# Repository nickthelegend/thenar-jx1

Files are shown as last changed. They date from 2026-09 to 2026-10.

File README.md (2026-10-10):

<p align="center">
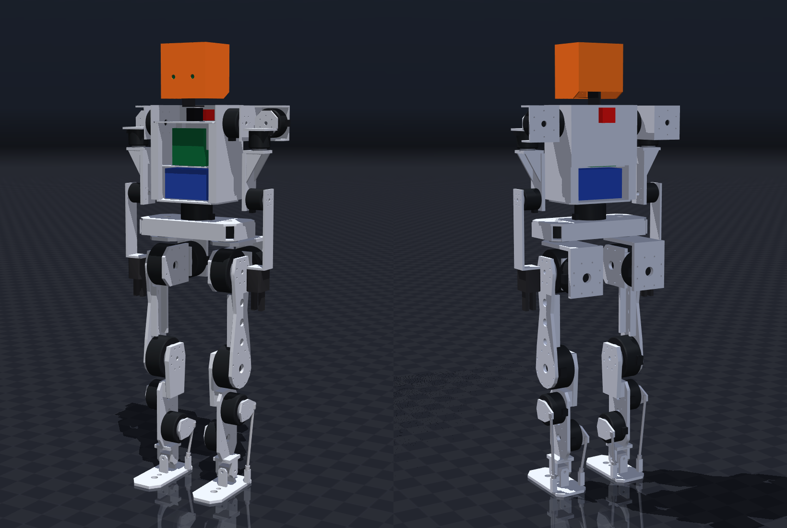
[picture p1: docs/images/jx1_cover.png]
JX1 humanoid robot, fully assembled — front three-quarter and back three-quarter views rendered from the CAD
  
</p>

<h1 align="center">JX1 — a humanoid robot you can build in India</h1>

<p align="center">
  <b>1.23 m tall · 33.6 kg · 23 joints · walks at 0.5–0.8 m/s in simulation · ≈ ₹7.1 lakh in parts</b><br>
  Full CAD, strength analysis, parts list with Indian suppliers, wiring, firmware, simulation and a trained walking
  controller, all in this repository.
</p>

<p align="center">
  <a href="docs/assembly_guide.md"><b>Assembly guide</b></a> ·
  <a href="docs/build_guide.md"><b>What to buy / machine / print</b></a> ·
  <a href="bom/cost_summary.md"><b>Cost</b></a> ·
  <a href="docs/final_robot_specification.md"><b>Specification</b></a> ·
  <a href="#try-it-in-simulation-free-no-hardware"><b>Try it in simulation</b></a> ·
  <a href="docs/open_issues.md"><b>Open issues</b></a>
</p>

---

## New: JX0, the small STS3215 humanoid you can build now

<p align="center">
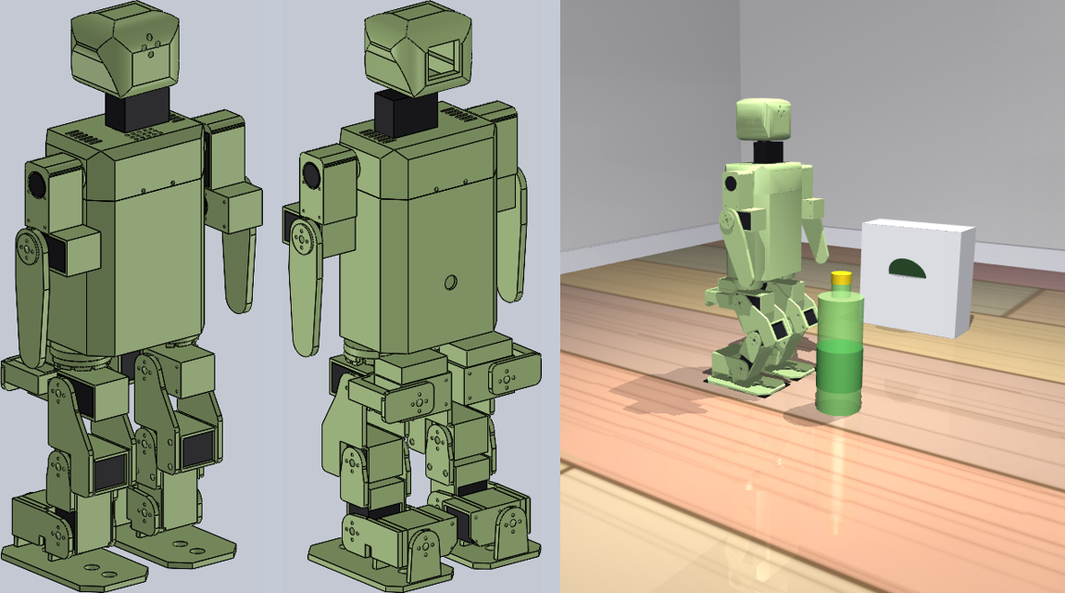
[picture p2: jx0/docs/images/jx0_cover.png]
JX0 v0.4: SolidWorks front and back views with double-sided leg joints, and the simulated robot walking with its arms swinging
  
</p>

JX1's parts cost about ₹7 lakh. **[JX0](jx0/README.md)** is the small version you can build now: 46 cm tall, printed
in pastel green, **every one of its 17 joints a Feetech STS3215 12 V servo**, styled after a friend's working robot,
with the same **double-sided leg joints** (every leg servo held on its horn and its rear hub by a U-bracket). It
**walks with its arms swinging, stays up through hard pushes, and talks (Claude)**, for **₹58,215** in parts. It uses
the same design pipeline as JX1:
- the SolidWorks CAD is built by script;
- the servo sizing passes;
- every printed leg part passes a finite-element check under the simulated walking and push loads;
- all 14 walking gaits pass in simulation;
- the robot's own program runs on the simulated robot.

<p align="center">
  <a href="jx0/README.md"><b>JX0 overview</b></a> ·
  <a href="jx0/results/images/jx0_demo.mp4"><b>Demo film</b></a> ·
  <a href="media/jx0_assembly.mp4"><b>Assembly film</b></a> ·
  <a href="jx0/bom/JX0_cost_estimate.pdf"><b>Cost estimate (8-page PDF)</b></a> ·
  <a href="jx0/docs/build_guide.md"><b>Build guide</b></a> ·
  <a href="jx0/results/verification.md"><b>Verification</b></a> ·
  <a href="media/jx0_cad_timelapse.mp4"><b>SolidWorks timelapse</b></a>
</p>

---

## Watch it go together

<p align="center">
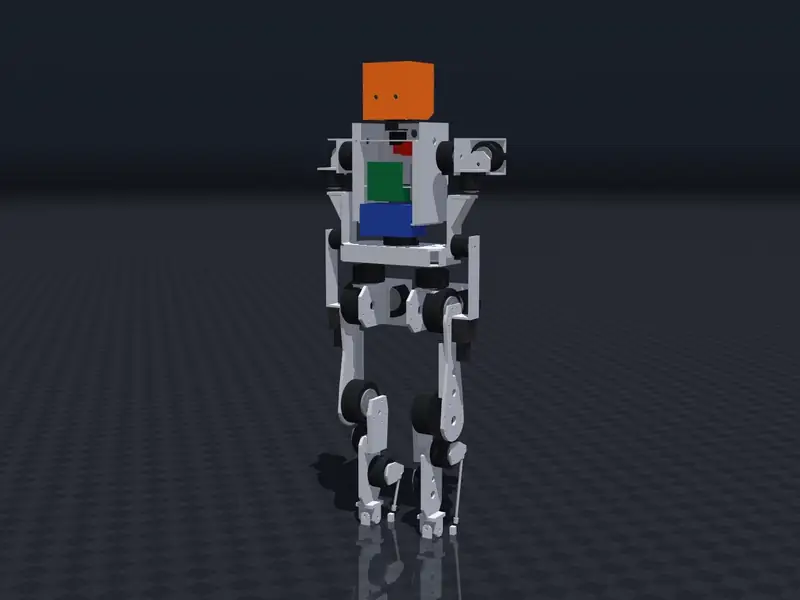
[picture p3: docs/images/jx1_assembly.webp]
Animated assembly of JX1: all 87 parts fly into place in build order, then the robot walks
  <br>
  <sub>Time-lapse of the assembly film. <b><a href="https://github.com/nickthelegend/thenar-jx1/raw/main/media/jx1_assembly.mp4">Download the full 96-second film with step titles (MP4, 13 MB)</a></b>:
  all 87 CAD parts come together in 22 steps, then the robot walks (MuJoCo simulation of the same CAD).</sub>
</p>

The film is rendered from the real SolidWorks parts in their verified positions (`tools/media/assembly_film.py`,
MuJoCo renderer). The titles are a [HyperFrames](https://hyperframes.heygen.com) composition synced to it
(`media/assembly-film/`). Every step is also written out with a picture in the
**[step-by-step assembly guide](docs/assembly_guide.md)**.

---

## Contents

1. [What is JX1?](#what-is-jx1)
2. [Honest status](#honest-status)
3. [JX1 at a glance](#jx1-at-a-glance)
4. [How JX1 works, in plain words](#how-jx1-works-in-plain-words)
5. [What it costs](#what-it-costs)
6. [What is metal, what is 3D-printed](#what-is-metal-what-is-3d-printed)
7. [How to build one: the whole path](#how-to-build-one-the-whole-path)
8. [Try it in simulation (free, no hardware)](#try-it-in-simulation-free-no-hardware)
9. [How it was designed and checked](#how-it-was-designed-and-checked)
10. [Repository map](#repository-map)
11. [Reproduce everything](#reproduce-everything)
12. [Glossary](#glossary)
13. [FAQ](#faq)
14. [Open issues, safety, licence](#open-issues-safety-licence)

---

## What is JX1?

JX1 is a **full-size walking humanoid robot**, about as tall as a 7-year-old child. It was designed from scratch to
answer one question:

> *What is the cheapest practical humanoid that someone in India can actually build, with parts they can actually
> buy, in shops they can actually reach?*

So every choice here favours buying over inventing, where that's possible:

- **Motors:** off-the-shelf RobStride actuators, the same kind small commercial humanoids use. There is no custom
  gearbox to design.
- **Structure:** flat aluminium plates that any laser-cutting or CNC job shop in India can cut from a drawing.
- **Electronics:** boards you can order from Robu, Evelta and similar shops.
- **Software:** open tools (MuJoCo, ROS 2, PyTorch). A walking controller is already trained and included.

Everything a builder needs is in the repository: 3D CAD (SolidWorks), STEP files and PDF drawings for the job shop,
strength calculations for every structural part, a costed parts list with Indian suppliers and links, wiring diagrams,
firmware for the motor-control boards, a physics simulation, and the trained walking policy.

## Honest status

**Current version: [v1.0-alpha](docs/releases/v1.0-alpha.md) (2026-09-24): design complete, buy list still being
decided.** JX1 has not been built yet. It is complete **on the computer**:

| Done (on the computer) | Not done yet (needs a real robot) |
|---|---|
| ✅ All 87 parts designed in CAD; every joint moved through its range and checked for collisions | ⬜ Actuator bolt patterns confirmed on real motors ([OI-1](docs/open_issues.md)) |
| ✅ Every structural part strength-checked (FEA), all pass in aluminium | ⬜ Real job-shop quotes (the metal prices are estimates) |
| ✅ Costed parts list, India-sourced | ⬜ Assembly, wiring, first power-on |
| ✅ Physics simulation: stands, squats, walks, survives pushes | ⬜ Walking on a real floor |
| ✅ Walking controller trained (reinforcement learning), tested on the full CAD model, over ROS 2 and against an emulated motor-control board | ⬜ Tuning on real hardware |

Every number in this repository carries a label, so you always know how much to trust it:
**VERIFIED** (checked against a source or a CAD measurement), **MEASURED**, **CALCULATED** (from a model),
**ESTIMATED**, **ASSUMED**, **UNVERIFIED**.

## JX1 at a glance

| | |
|---|---|
| Height, mass | 1.23 m, 33.6 kg (CAD, all parts) |
| Joints (degrees of freedom) | **23**: legs 2 × 6, waist 1, arms 2 × 4, neck 2 |
| Legs | hip yaw, roll and pitch meet at one point; knee; **parallel ankle** (2 motors on the shin drive the foot through push-rods) |
| Motors | 21 × RobStride (RS04 120 N·m, RS03 60 N·m, RS06 36 N·m, RS02 17 N·m, RS00 14 N·m peak) + 2 bus servos in the neck |
| Brain | NVIDIA Jetson Nano 4 GB: runs the walking controller 50 times a second |
| Motor control | 2 × Teensy 4.1 "hub" boards, 6 CAN buses, 500 updates per second |
| Sensors | BNO085 IMU (balance) in the pelvis, IMX219-83 stereo camera in the head, encoders in every motor |
| Battery | 13S2P Li-ion, 48 V nominal, 468 Wh: ≈ 1.4 h walking at 0.5 m/s (1.1 h at 0.8 m/s), ≈ 5 h standing (CALCULATED) |
| Structure | 6061-T6 aluminium plates (7075-T6 for the hip-yaw brackets); head and grippers 3D-printed |
| Walking (simulation) | learned controller: trained up to 0.8 m/s forward, side-steps ±0.39 m/s, turns up to 0.87 rad/s; survives 29–60 N·s shoves while walking, 26–55 N·s standing; stands still at 73 W. Scripted gait: 0.3–0.52 m/s |
| Cost | ₹7,12,481 in parts (₹8,19,353 with 15 % contingency); the motors are 77 % of it |

Full details: the generated **[FINAL ROBOT SPECIFICATION](docs/final_robot_specification.md)**.

## How JX1 works, in plain words

Think of the robot like a body:

| Body part | In JX1 | What it does |
|---|---|---|
| **Skeleton** | aluminium plates and brackets | holds everything in place and carries the robot's weight |
| **Muscles** | 21 *actuators*: motor + gearbox + position sensor + driver in one round can | each one turns one joint to the angle it is told, with the stiffness it is told |
| **Nerves** | CAN bus: two twisted wires that daisy-chain from motor to motor | carries commands out and joint angles back, 500 times a second |
| **Spinal cord** | 2 × Teensy 4.1 hub boards | talk to the motors fast and safely, and stop everything if something goes wrong |
| **Brain** | Jetson Nano running a neural-network *policy* | decides where each leg joint should go next, 50 times a second |
| **Inner ear** | IMU in the pelvis | senses tilt and rotation, so the robot knows if it is falling |
| **Eyes** | stereo camera in the head | depth vision (for later: navigation and manipulation) |
| **Heart** | 468 Wh battery + BMS + fuses | feeds 48 V to the motors and 5 V to the computers |
| **Reflex** | red E-stop button | cuts motor power and makes every joint go soft |

```mermaid
flowchart LR
  CMD["Joystick / ROS 2<br/>'walk forward 0.5 m/s'"] --> J["Jetson Nano<br/>walking policy, 50 Hz"]
  J -- "USB: joint targets" --> HA["Hub A (Teensy 4.1)<br/>left leg, left arm, waist"]
  J -- "USB: joint targets" --> HB["Hub B (Teensy 4.1)<br/>right leg, right arm, neck"]
  HA -. "joint states + IMU" .-> J
  HB -. "joint states" .-> J
  IMU["IMU in pelvis"] -- SPI --> HA
  HA -- "3 CAN buses, 500 Hz" --> MA["11 actuators"]
  HB -- "3 CAN buses, 500 Hz" --> MB["10 actuators"]
  MA -- "joint angles + speeds" --> HA
  MB -- "joint angles + speeds" --> HB
  ES["E-stop"] -. "cuts motor power + damping" .-> HA
  ES -.-> HB
```

**How it walks.** Nobody hand-wrote the walking. A neural network (the *policy*) learned to walk by trial and error in
a physics simulation of the exact CAD robot. The method is reinforcement learning (PPO), about 20,000 simulated steps
per second on one laptop. The policy was trained with random pushes, rough ground, small sensor delays, and randomised
friction and masses, so it doesn't depend on the simulation being perfect. Every 20 ms it reads the joint angles and the IMU and
outputs a target angle for each of the 12 leg joints. The motors then hold those angles like stiff springs. See
[rl/README.md](rl/README.md).

**Where the joints are.**

| Joint | Per side | Actuator | Range (left side) |
|---|---|---|---|
| Hip yaw (turn the leg) | 1 | RS06 | −40° … +45° |
| Hip roll (leg out to the side) | 1 | RS03 | −25° … +45° |
| Hip pitch (leg forward/back) | 1 | RS04 | −115° … +35° |
| Knee | 1 | RS04 | 0° … 120° |
| Ankle pitch + roll (parallel: 2 motors together) | 2 | 2 × RS06 | −55° … +30°, ±20° |
| Waist yaw | (1 total) | RS06 | ±90° |
| Shoulder pitch / roll | 2 | 2 × RS02 | −170° … +60° / −10° … +150° |
| Shoulder yaw / elbow | 2 | 2 × RS00 | ±90° / −135° … +5° |
| Neck yaw + pitch | (2 total) | 2 × ST3215 servo | — |

The single source of truth for joint names, axes, limits and motor directions is
[`simulation/joint_map.yaml`](simulation/joint_map.yaml). The CAD, simulation, ROS 2 and firmware are all generated
from it or checked against it.

## What it costs

Landed cost in India, including GST and import duty (from [`bom/master_bom.csv`](bom/master_bom.csv); prices checked
2026-09; metal parts ESTIMATED until quoted):

| Group | ₹ | What's in it |
|---|---:|---|
| Legs | 4,18,394 | 12 actuators + metal leg parts + ankle linkage |
| Arms | 1,52,688 | 8 actuators + arm plates |
| Electronics | 49,048 | Jetson Nano, 2 × Teensy 4.1, IMU, CAN parts, camera |
| Power | 31,606 | battery cells, BMS, switch, E-stop, fuses, DC-DC |
| Torso | 31,522 | waist actuator, torso frame |
| Head, pelvis, manufacturing | 29,223 | head shell + neck servos, pelvis box, filament and consumables |
| **Total** | **7,12,481** | + 15 % contingency = **₹8,19,353** |

- **Printable 9-page component list and cost estimate:** [bom/JX1_cost_estimate.pdf](bom/JX1_cost_estimate.pdf) (generated from the BOM by `bom/make_cost_report.py`).
- **Motors are 77 % of the cost** (₹5,45,998). Buying the same RobStride units through a China distributor would save
  about ₹1.87 lakh ([cost summary](bom/cost_summary.md)).
- **You can build it in two phases.** Phase 1 is the walking lower body (legs + pelvis + compute + power) for about
  ₹5.1 lakh. The upper body comes later.

## What is metal, what is 3D-printed

**Short answer: don't 3D-print the skeleton.** Every structural part was strength-checked both ways. Aluminium passes
everywhere. Printed carbon-fibre nylon (PA-CF) fails everywhere, and PETG would be worse.

| Printed PA-CF safety factor | Aluminium safety factor (needs ≥ 1.5) |
|---|---|
| hip-yaw bracket **0.08** ❌ | 7075-T6: **1.77** ✅ |
| shin **0.35** ❌ | 6061-T6: **3.37** ✅ |
| pelvis **0.90** ❌ | 6061-T6: **2.90** ✅ |
| upper arm **0.73–1.23** ❌ | 6061-T6: **5.99** ✅ |

What you **do** print:

1. **PETG fit-check copies** of every metal part (`manufacturing/fit_check/`). Bolt them to the real motors first to
   check the holes and clearances. Then order the metal. This is cheap insurance.
2. **Real printed parts** that carry little load: the head shell (PETG-CF), neck bracket and grippers (PA-CF, TPU
   pads), covers and battery box.

The full table (every part, material, process, file) is in the **[build guide](docs/build_guide.md)**. STEP files
and A3 PDF drawings for the job shop are in **[manufacturing/](manufacturing/index.md)**.

## How to build one: the whole path

You don't need to be an expert, but you need patience and care. The high-power parts (48 V, 468 Wh battery,
120 N·m motors) can hurt you. Go in this order:

| # | Stage | What you do | Guide |
|---|---|---|---|
| 0 | **Understand it** | read this page, watch the film, run the simulation | [simulation](#try-it-in-simulation-free-no-hardware) |
| 1 | **Lock the motor interfaces** | get the official RobStride drawings (or measure one of each size), put the bolt patterns into `tools/cad/params.py`, regenerate the CAD | [build guide §6](docs/build_guide.md#6-build-order), [OI-1](docs/open_issues.md) |
| 2 | **Bench electronics** | one motor on a USB-CAN adapter: set its ID, read feedback; flash the Teensy hub firmware; test the E-stop | [electrical wiring §6](docs/electrical_wiring.md#6-bring-up-checklist-electrical), [`firmware/`](firmware/) |
| 3 | **Fit-check prints** | print the PETG copies, bolt them to the real motors, fix anything that doesn't fit | [build guide §4](docs/build_guide.md#4-printing-notes) |
| 4 | **Order parts** | send the STEP + PDF set to a laser/CNC shop; buy the motors and electronics from the BOM | [manufacturing/](manufacturing/index.md), [BOM](bom/master_bom.csv) |
| 5 | **Assemble** | 22 steps: pelvis → hips → thighs → knees → shins → ankles → feet → waist → torso → electronics → arms → head | **[assembly guide](docs/assembly_guide.md)** |
| 6 | **Wire it** | power trunks with 58 V fuses, 6 CAN buses, E-stop with two independent paths | [electrical wiring](docs/electrical_wiring.md) |
| 7 | **First power-on** | on a gantry, feet off the ground: one joint at a time, zero offsets, limits, motor directions | [assembly guide, part E](docs/assembly_guide.md#part-e--after-the-assembly-first-power-on-the-safe-order), [safety](docs/safety_architecture.md) |
| 8 | **Stand, then walk** | still on the harness: damping → stand → weight shifts → the learned walking policy over ROS 2 | [rl/README.md](rl/README.md#real-robot-hardware-bridge-and-hardware-in-the-loop-ros2_wssrcjx1_hw) |

**The 22 assembly steps** (each one has a picture and instructions in the [assembly guide](docs/assembly_guide.md)):

| Lower body | | Torso, power, arms, head | |
|---|---|---|---|
| 1 | Pelvis torsion box | 13 | Waist actuator |
| 2 | Hip-yaw actuators | 14 | Torso frame |
| 3 | Hip-yaw brackets (7075) | 15 | Battery + electronics |
| 4 | Hip-roll actuators | 16 | Shoulder-pitch actuators |
| 5 | Hip-roll brackets | 17 | Shoulder brackets + roll actuators |
| 6 | Hip-pitch actuators | 18 | Shoulder-yaw actuators |
| 7 | Thighs | 19 | Upper arms + elbows |
| 8 | Knee actuators | 20 | Forearms + grippers |
| 9 | Shins | 21 | Neck |
| 10 | Ankle motors + cranks | 22 | Head + stereo camera |
| 11 | Ankle cross + feet | | |
| 12 | Push-rods | | |

<p align="center">
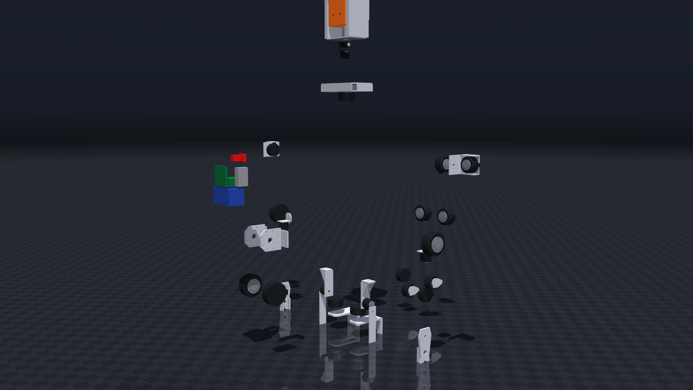
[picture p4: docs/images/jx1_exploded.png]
JX1 exploded view
  
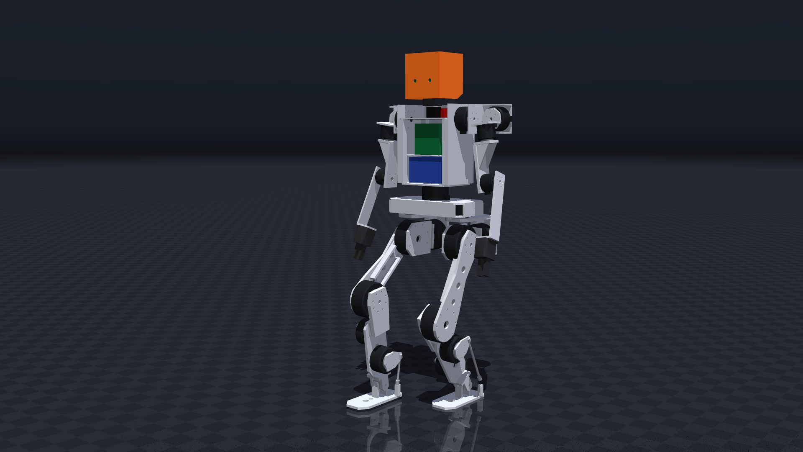
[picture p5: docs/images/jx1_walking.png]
JX1 walking in simulation
  
</p>

## Try it in simulation (free, no hardware)

You can drive the robot around with your keyboard in about five minutes. Any recent Windows, Linux or Mac computer
works. No GPU is needed to *run* the trained controller.

```bash
git clone https://github.com/nickthelegend/thenar-jx1.git
cd thenar-jx1
python -m venv rl/.venv
```

Then install and start it. On **Windows**:

```bash
rl/.venv/Scripts/python -m pip install -r rl/requirements.txt
rl/.venv/Scripts/python rl/play.py
```

On **Linux / macOS** (on macOS, use `mjpython` from the same venv instead of `python` for the viewer):

```bash
rl/.venv/bin/python -m pip install -r rl/requirements.txt
rl/.venv/bin/python rl/play.py
```

A MuJoCo window opens with the full CAD robot standing on the floor. Click the window, then:

| Key | Does |
|---|---|
| ↑ / ↓ | walk faster forward / backward (0.1 m/s per press) |
| ← / → | turn left / right |
| `,` / `.` | step sideways |
| Space | stop |
| Backspace | reset to standing |

Want more? `rl/sim2sim.py` runs the standard test scenarios. `rl/push_test.py` shoves the robot.
`rl/train.py` trains your own policy (a GPU helps). ROS 2 users: `ros2 launch jx1_bringup mujoco_sim.launch.py` and
drive `/cmd_vel`. All of it is in **[rl/README.md](rl/README.md)**.

## How it was designed and checked

The design went through the same loop a professional team would use. Each step leaves evidence files in the repo:

```text
requirements ─► reference robots (29 humanoids) ─► actuator selection ─► leg maths (IK, ZMP walking, dynamics)
     ─► parametric CAD (SolidWorks, driven from Python) ─► every joint moved through its range, collisions checked
     ─► strength (voxel FEA, every structural part, static + fatigue) ─► mass + cost roll-up ─► back to the start
     ─► simulation model generated from the CAD ─► walking, pushes ─► reinforcement-learning controller ─► ROS 2 + firmware
```

| Area | Result | Evidence |
|---|---|---|
| CAD | 46 native parametric parts, fully constrained sketches, global variables; `JX1_LowerBody`, `JX1_UpperBody`, `JX1_Robot` assemblies with limit-mated joints | `CAD/`, `verification/cad_build_*.json` |
| Motion verification (SolidWorks vs analytic kinematics) | legs 25/25 poses each at 0.0000 mm / 0.0000°, 24/24 collision-free inside the coupled ankle limits; upper body 36/36 exact and collision-free; whole robot 13/13 exact, 11/11 collision-free inside the controller limits (pre-arm-redesign, OI-25); overhead arm range checked in MuJoCo on the CAD shapes, 49/49 agreement with SolidWorks (OI-16) | `verification/*motion_verification.json`, `verification/mujoco_arm_range.json`, images |
| Structure (voxel FEA, actuator-capped loads) | every structural part passes in 6061/7075 (SF static 1.77–14.4, fatigue 1.58–24.7); every printed PA-CF variant fails (0.07–1.23) | [structural report](calculations/results/structural/report.md) |
| Actuator margins (CAD masses) | at 0.8 m/s the learned controller keeps hips and knees within the 1.5× peak-torque policy (knee 89 of 120 N·m, hip roll 48 of 60); the ankle motors are the tightest: ankle pitch at 82 % of the linkage capability, capped at 80 % by the hub firmware (OI-21); the scripted ZMP gait meets it up to 0.52 m/s, at 0.79 m/s its hip yaw needs 37 N·m vs 36 N·m (OI-2) | [final spec](docs/final_robot_specification.md), `calculations/results/iter2_C_cad_masses/` |
| Simulation | MuJoCo model from the CAD (33.61 kg, CoACD hulls): standing, squat, ZMP walking 4/4 gaits, push recovery; URDF + xacro | `verification/mujoco_*.json`, `verification/xacro_check.json` |
| Learned walking | default `jx1_walk_stand_v7`: 8/8 scenarios upright on flat and rough ground (0.8 m/s command → 0.75–0.77 m/s), 118/130 (flat) and 119/130 (rough) commands tracked with 0 falls, pushes 29–60 N·s walking and 26–55 N·s standing, stands still (0 foot lift-offs); verified over ROS 2 and through the hub-firmware twin (HIL: 0.68 m/s at a 0.8 m/s command with the 80 % torque caps). Weak spot: slow forward walking undershoots (84 % of 0.3 m/s through the HIL chain, 93 % of 0.4 m/s over ROS 2). Isaac Lab task offline-checked, not run (UNVERIFIED) | [rl/README.md](rl/README.md), `rl/policies/jx1_walk_stand_v7/REPORT.md` |
| Manufacturing | 24 STEP files, 14 A3 drawings (PDF), 24 PETG fit-check STLs, 3 print STLs | [manufacturing/index.md](manufacturing/index.md) |
| Cost (India, landed) | ₹7,12,481; ₹8,19,353 with 15 % contingency; actuators 77 % | [bom/cost_summary.md](bom/cost_summary.md) |
| Power | 13S2P 468 Wh with the learned controller: standing 73 W → 5.1 h; walking 274 W at 0.5 m/s → 1.37 h, 347 W at 0.8 m/s → 1.08 h; peak battery current 15.9 A (BMS limit 40 A) | `rl/policies/jx1_walk_stand_v7/power.json`, `calculations/results/iter2_C_cad_masses/power_budget.json` |

## Repository map

| Folder | What's inside |
|---|---|
| [`docs/`](docs/) | **start here**: [assembly guide](docs/assembly_guide.md), [build guide](docs/build_guide.md), [final spec](docs/final_robot_specification.md), [architecture](docs/architecture.md), [electrical wiring](docs/electrical_wiring.md), [safety](docs/safety_architecture.md), [risk register](docs/risk_register.md), [open issues](docs/open_issues.md) |
| [`manufacturing/`](manufacturing/index.md) | files for the job shop: STEP, PDF drawings, PETG fit-check STLs, print STLs |
| [`bom/`](bom/) | [master_bom.csv](bom/master_bom.csv) (every part, supplier, link, price), [cost_summary.md](bom/cost_summary.md) |
| `CAD/` | native parametric SolidWorks parts and assemblies (`JX1_Robot`, `JX1_LowerBody`, `JX1_UpperBody`), drawings |
| `calculations/` | leg model, inverse kinematics, ZMP walking, dynamics, parallel ankle, power budget; `structural/` voxel FEA |
| [`actuators/`](actuators/actuator_selection.md) | why these motors: selection study, interface spec, catalogue |
| [`research/`](research/reference_robots.md) | 29 reference humanoids, Indian sourcing evidence |
| `requirements/` | [robot_requirements.yaml](requirements/robot_requirements.yaml): the living requirements |
| `simulation/` | [`joint_map.yaml`](simulation/joint_map.yaml) (kinematic contract), MuJoCo model and tests, Isaac Sim/Lab, meshes |
| [`rl/`](rl/README.md) | walking-controller training, export, tests, trained policies |
| `ros2_ws/` | ROS 2 packages: description (URDF/xacro), simulation node, policy node, bringup, hardware bridge |
| `firmware/` | Teensy 4.1 CAN-hub firmware: RobStride protocol, 500 Hz loop, watchdogs, E-stop |
| `tools/` | Python that drives SolidWorks (`swlib`, `cad`), builds the robot description (`sim`), renders the film (`media`) |
| `media/` | the assembly film ([jx1_assembly.mp4](media/jx1_assembly.mp4)) and its HyperFrames project |
| `verification/` | machine-readable evidence (JSON) and images for every check |

## Reproduce everything

Analysis (no SolidWorks needed):

```bash
python -m venv .venv
.venv/Scripts/python -m pip install -r requirements.txt
.venv/Scripts/python calculations/tests/test_kinematics.py
.venv/Scripts/python calculations/structural/test_voxel_fea.py
.venv/Scripts/python calculations/structural/run_structural.py
.venv/Scripts/python bom/build_bom.py
.venv/Scripts/python simulation/mujoco/validate_jx1.py
.venv/Scripts/python simulation/mujoco/walk_jx1.py
.venv/Scripts/python simulation/mujoco/push_jx1.py
.venv/Scripts/python tools/gen_final_spec.py
```

CAD (SolidWorks 2026 on Windows, driven through COM in a **dedicated session**, `tools/swlib/instance.py`, so other
SolidWorks work on the same machine is never touched; restart the JX1 session between the heavy steps, since the
whole-robot assembly needs ≈ 10 GB):

```bash
.venv/Scripts/python tools/cad/build_actuators.py XL L M S XS
.venv/Scripts/python tools/cad/build_leg_parts.py --side L
.venv/Scripts/python tools/cad/build_leg_parts.py --side R
.venv/Scripts/python tools/cad/build_upper_parts.py
.venv/Scripts/python tools/cad/build_upper_parts.py --side R
.venv/Scripts/python tools/cad/build_leg_assembly.py --sides LR
.venv/Scripts/python tools/cad/verify_leg_motion.py --side L --images
.venv/Scripts/python tools/cad/build_upper_assembly.py
.venv/Scripts/python tools/cad/verify_upper_motion.py --images
.venv/Scripts/python tools/cad/build_robot_assembly.py
.venv/Scripts/python tools/cad/verify_robot_motion.py --images
.venv/Scripts/python tools/cad/export_meshes.py
.venv/Scripts/python tools/cad/make_manufacturing.py
.venv/Scripts/python tools/sim/build_robot_description.py
.venv/Scripts/python tools/sim/check_xacro.py
```

The assembly film (MuJoCo render of the CAD, then the HyperFrames titles; needs ffmpeg and Node.js):

```bash
.venv/Scripts/python tools/media/assembly_film.py
.venv/Scripts/python tools/media/assembly_film.py --hero
.venv/Scripts/python tools/media/build_assembly_composition.py
cd media/assembly-film && npx hyperframes check && npx hyperframes render -o renders/jx1_assembly_master.mp4
```

RL training, export and the ROS 2 checks: [rl/README.md](rl/README.md).

## Glossary

| Word | Meaning |
|---|---|
| **Actuator** | a complete joint motor: brushless motor + planetary gearbox + position sensor (encoder) + driver electronics in one can. You send it a target angle and stiffness over CAN. |
| **DOF (degree of freedom)** | one way a joint can move. A human elbow has 1, a shoulder 3. JX1 has 23. |
| **Yaw / roll / pitch** | rotation about the vertical axis (turning), the forward axis (tilting sideways) and the sideways axis (nodding forward/back). |
| **Parallel ankle** | the ankle is moved by two motors mounted up on the shin, through two push-rods. The foot is light, and both motors share the load. |
| **N·m (newton-metre)** | torque, i.e. turning force. 120 N·m is like 12 kg hanging on a 1 m bar. |
| **FEA (finite element analysis)** | computer strength check: split a part into tiny cubes, apply the worst loads, find the highest stress. |
| **Safety factor (SF)** | strength ÷ worst stress. SF 2 means the part could take twice the worst load. JX1 requires ≥ 1.5 for aluminium, ≥ 2 for prints. |
| **Static / fatigue** | one big overload (a hard landing) / millions of small repeated loads (walking). Both have to pass. |
| **6061-T6 / 7075-T6** | common aerospace aluminium alloys. 7075 is about twice as strong and costs more. |
| **PETG, PA-CF, TPU** | 3D-printing plastics: everyday, carbon-fibre nylon (stiff and strong for a print), rubbery. |
| **STEP / STL / PDF drawing** | exact 3D model for machining / triangle mesh for 3D printing / 2D drawing with dimensions and tolerances. |
| **CAN bus** | a robust two-wire network used in cars. JX1 has 6 of them, each chaining 3–5 motors. |
| **BMS** | battery management system: protects the cells from over-charge, over-discharge and over-current. |
| **E-stop** | emergency stop: a big red button that cuts motor power and makes every joint go limp. |
| **IMU** | inertial measurement unit: senses rotation and acceleration, which is how the robot knows which way is down. |
| **ZMP** | zero-moment point: the classic way to plan a walking gait so the robot doesn't tip over. Used for the scripted gait. |
| **RL / PPO / policy** | reinforcement learning: the controller learns by trial and error in simulation. PPO is the algorithm. The result is a small neural network called the policy. |
| **Sim-to-sim** | testing the trained policy in a different, more detailed simulation than the one it was trained in: a check before trying it on hardware. |
| **HIL (hardware-in-the-loop)** | running the real control software against a software twin of the motor boards, to catch protocol and timing bugs early. |
| **URDF / xacro / MJCF** | robot description files (links, joints, masses, meshes) for ROS 2 / its macro form / MuJoCo. |
| **ROS 2** | Robot Operating System 2: the standard middleware robots use to pass messages between programs. |
| **MuJoCo** | a fast, accurate physics simulator, used here for testing and for training. |
| **Zero pose** | legs straight, feet flat, arms down: the reference where every joint angle is 0. |

## FAQ

**Can I build it with no engineering background?**
Yes, if you're careful and patient and have access to basic tools and a job shop for the metal. The assembly is
bolting parts together in the order of the [assembly guide](docs/assembly_guide.md). The hard engineering (sizing,
strength, kinematics, control) is already done and checked. The parts that can hurt you are the 48 V battery and
motors strong enough to pinch a finger badly. Read the [safety architecture](docs/safety_architecture.md) and always
test on a gantry.

**Can I 3D-print the whole thing to save money?**
No. The legs, pelvis, torso and arms fail the strength check as prints. A printed hip-yaw bracket would break at 8 % of
the worst load. See [what is metal, what is printed](#what-is-metal-what-is-3d-printed). Print the fit-check copies,
the head, the grippers and the covers.

**Why is it so expensive? Can I use cheaper motors?**
The 21 motors are 77 % of the cost. Each one is a complete joint: a high-torque brushless motor, a precision
planetary gearbox, bearings, an absolute encoder and a motor driver in one machined can. A walking humanoid's hips and
knees need 60–120 N·m peak torque while staying back-drivable, which hobby servos can't give. Of the ₹5.46 lakh,
₹3.86 lakh is RobStride's list price, ₹1.25 lakh is import duty (about 32 %: customs duty, surcharge and 18 % IGST) and
₹0.36 lakh is shipping; none are stocked in India. They are still the cheapest option found: ₹290 per N·m of peak
torque for the RS04, against ₹2,200–7,900 per N·m for integrated actuators sold in India
([actuator study](actuators/actuator_selection.md)). The cheapest real saving is buying the same RobStride units through
a China distributor (≈ ₹1.87 lakh less). A cheaper actuator can go in: the CAD is
parametric, so you change the actuator class in `tools/cad/params.py` and regenerate, then re-run the checks.

**Do I need SolidWorks?**
Only to *change* the design. To build it, you use the STEP files and PDF drawings in `manufacturing/`, which any CAD
program or job shop can open. The simulation, strength checks, BOM and controller all run without SolidWorks.

**Where do I buy things in India?**
Every line of [`bom/master_bom.csv`](bom/master_bom.csv) has a supplier and a link: Robu, Evelta, IndustryBuying,
bearinghouse.in and others. Metal parts go to a laser/CNC job shop (e.g. Robocon CNC, Makenica, or a local shop) with
the STEP + PDF set.

**How fast does it walk? How long does the battery last?**
In simulation the learned controller walks at up to 0.8 m/s (1.09 m/s at the edge of its range) and turns at up to
0.87 rad/s. The battery gives about 1.4 hours of walking at 0.5 m/s, or about 5 hours of standing (CALCULATED).
Real-world numbers will come from the first build.

**What is still unknown?**
Mainly the exact actuator bolt patterns (OI-1), real job-shop prices, and everything only a physical robot can show:
friction, backlash, cable wear, real walking. The full list is in [open issues](docs/open_issues.md) and the
[risk register](docs/risk_register.md).

**Can I help?**
Yes. Build parts of it, measure a RobStride actuator, get a job-shop quote, or try the controller. Anything that closes
an item in [open issues](docs/open_issues.md) moves the project forward.

## Open issues, safety, licence

- **Top open items:** actuator interface dimensions (OI-1); hip-yaw actuator vs top walking speed for the scripted gait
  (OI-2); bolted plate joints: CAD fastener geometry and prototype strain check (OI-17); drawings made under a
  SolidWorks Educational licence carry its "For Instructional Use Only" stamp (OI-19); whole-robot SolidWorks assembly
  re-check after the arm redesign (OI-25); ankle-motor torque headroom at the top walking speed, to be bench-checked
  (OI-21). All of them are in
  [open issues](docs/open_issues.md).
- **Safety:** this is a 34 kg machine with 120 N·m joints and a 468 Wh lithium battery. Always use the E-stop, a
  gantry or harness, and current-limited power for bring-up. See [safety architecture](docs/safety_architecture.md).
- **Licence:** not chosen yet. Until a licence file is added, ask the author before reusing the design commercially
  (OI-19).

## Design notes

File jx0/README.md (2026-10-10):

<p align="center">
  JX0 v0.4: SolidWorks front and back views with double-sided leg joints, and the simulated robot walking with its arms swinging
</p>

<h1 align="center">JX0: a walking, talking STS3215 humanoid you can build at home</h1>

<p align="center">
  <b>46 cm · 2.88 kg · 17 joints, every one a Feetech STS3215 12 V · double-sided leg joints · walks with its arms
  swinging · talks (Claude) · ₹58,215 in parts</b><br>
  3D-printed in pastel green, styled after a friend's working STS3215 robot. Full SolidWorks CAD, a verified walking
  simulation, a strength check of every leg part, the robot program and a parts list with Indian suppliers are all in
  this folder.
</p>

<p align="center">
  <a href="docs/build_guide.md"><b>Build guide</b></a> ·
  <a href="bom/jx0_bom.csv"><b>Parts list</b></a> ·
  <a href="bom/JX0_cost_estimate.pdf"><b>Cost estimate (8-page PDF)</b></a> ·
  <a href="../media/jx0_assembly.mp4"><b>Assembly film</b></a> ·
  <a href="docs/wiring.md"><b>Wiring</b></a> ·
  <a href="docs/bringup.md"><b>Bring-up</b></a> ·
  <a href="docs/software_setup.md"><b>Software</b></a> ·
  <a href="results/verification.md"><b>Verification</b></a> ·
  <a href="#try-it-on-your-pc">Try it on your PC</a>
</p>

---

## Watch it

<p align="center">
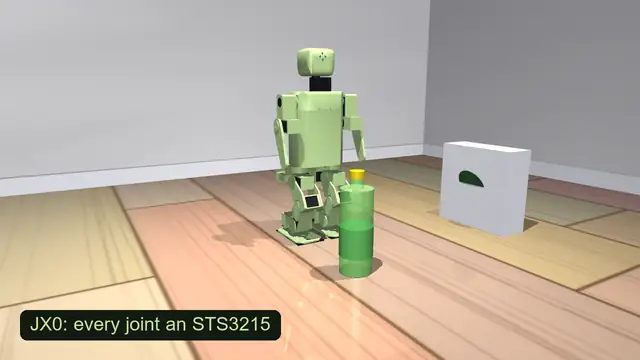
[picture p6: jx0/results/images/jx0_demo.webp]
Simulated JX0 waving, walking with its arms swinging, taking a hard side push and bumping a bottle out of its way
  <br>
  <sub><b><a href="results/images/jx0_demo.mp4">Demo film (MP4)</a></b>, staged like the reference video: JX0 walks on
  a wooden floor with its arms swinging, waves, takes a hard 0.96 N·s shove from the side and keeps going (in the
  <a href="results/verification.md">verification</a> it stays up through all 48 such shoves, timed across a whole
  step), and bumps a plastic bottle out of its way. The robot's own program (<code>software/jx0bot</code>, the same code that runs
  on the Pi) drives the SolidWorks robot in MuJoCo; the push and the bottle are plain physics.</sub>
</p>

## Watch it go together

<p align="center">
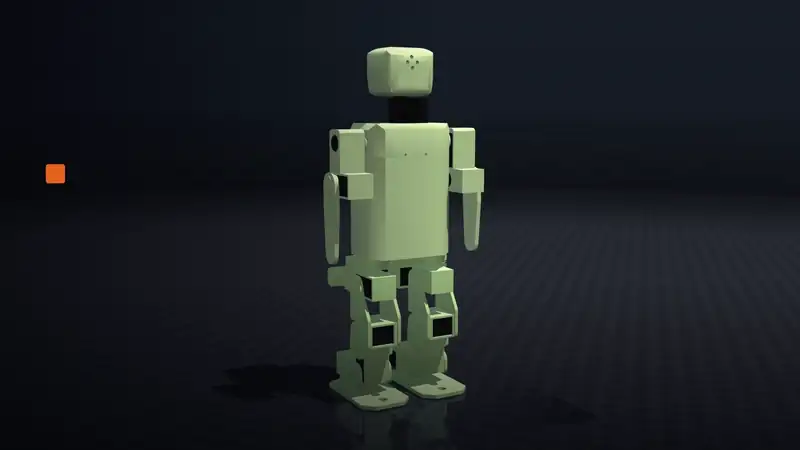
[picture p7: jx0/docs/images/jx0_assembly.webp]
Animated assembly of JX0: its 39 parts fly into place in build order, then the robot walks
  <br>
  <sub><b><a href="../media/jx0_assembly.mp4">Assembly film (MP4, 67 s)</a></b>: every SolidWorks part of JX0 flies into
  place in the order of the <a href="docs/build_guide.md">build guide</a>, 13 steps from the pelvis to the head, then the
  finished robot walks its verified gait. Rendered from the real part meshes (<code>tools/media/assembly_film_jx0.py</code>,
  MuJoCo) with HyperFrames titles (<code>media/jx0-assembly-film</code>), like the JX1 film. A still of every step:
  <code>docs/assembly/</code>.</sub>
</p>

<p align="center">
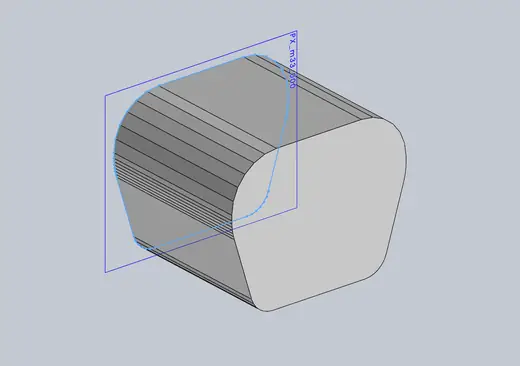
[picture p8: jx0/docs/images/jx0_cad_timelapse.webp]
SolidWorks timelapse: the JX0 parts built feature by feature, then the assembly
  <br>
  <sub>Built in SolidWorks by script (<code>cad/build_cad.py</code>, <code>cad/build_assembly.py</code>). The timelapses
  show the earlier single-sided legs: <a href="../media/jx0_cad_timelapse_v03.mp4">v0.3 (81 s)</a> ·
  <a href="../media/jx0_cad_timelapse.mp4">every version up to v0.3 (117 s)</a>.</sub>
</p>

## The legs: double-sided, like the reference robot

<p align="center">
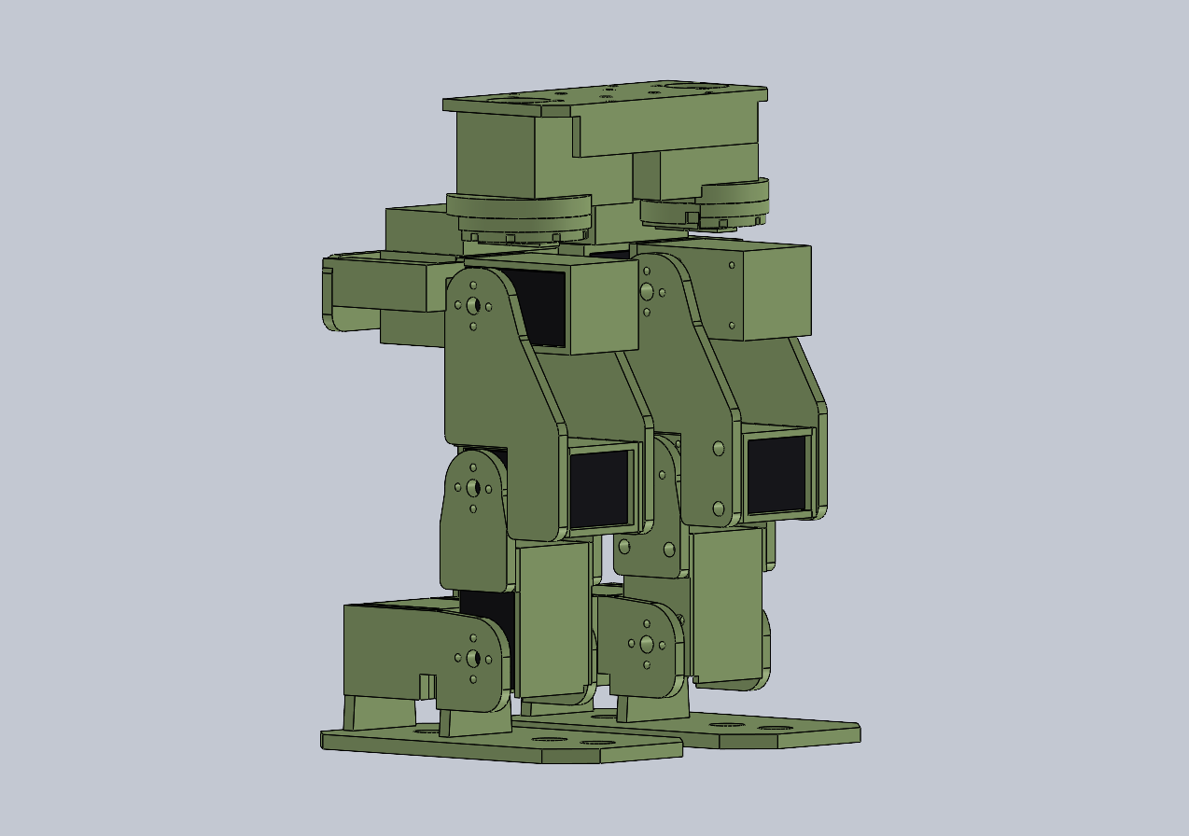
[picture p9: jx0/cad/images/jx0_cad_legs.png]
JX0 v0.4 legs in SolidWorks: every servo in a cage, the next part a U-bracket bolted to both faces of it
  
</p>

A servo joint can hold the next part in two ways:

- **Single-sided** (JX0 v0.3): the next part is one plate screwed to the servo's output horn. Every step bends that
  plate and the servo's output shaft. The plate is a cantilever, and printed plastic tires quickly when it is bent
  back and forth.
- **Double-sided** (v0.4, the reference robot): the STS3215 has a second, passive hub on its back face. The next part
  is a **U-bracket** with one arm on the horn and one on the rear hub, and the servo's body sits in a **cage** on the
  part before. The bending becomes a pair of forces in two arms 43 mm apart, and the servo's shaft is not bent at all.

The check (`verify/verify_strength.py`, `verify/verify_fea.py`) uses the loads from the walking simulation, every
10 ms, including 48 hard pushes and 42 walks on a randomly wrong robot model:

| | v0.3 single-sided plates | v0.4 U-brackets |
|---|---|---|
| Printed plate stress, walking | 30–85 MPa | 2–5 MPa |
| Fatigue safety factor (PETG ~15 MPa at 10⁶ cycles, ASSUMED) | **0.21–0.48: would crack** | **4.4–7.5** (beam model) |
| Servo output shaft bending (worst) | 2.3–3.6 N·m at every joint | none at the U-brackets; 0.55 N·m at the hip yaw (keeper) |
| Finite elements, every printed leg part | — | fatigue safety factor **2.1 or more**, strength **3.0 or more** |

The **hip yaw** cannot be a U-bracket: its servo stands under the body, as on the reference robot, with the hip-roll
servo right below it. So the pelvis holds the yaw disc from both sides instead:
- a **thrust ring** above the disc;
- a printed **keeper** below it, one per leg, whose lip runs under the disc's 3 mm flange. Four M2 screws clamp it to a
  boss on the pelvis.

The ring and the keeper take the leg's weight and bending as two pushes on the disc's rim, instant by instant
(`robustness.keeper_split`). The yaw servo's shaft is left with:

| | Normal walking | Hardest pushes |
|---|---|---|
| Thrust ring alone | 1.2 N·m | 2.6 N·m |
| Thrust ring + keeper | **0.10 N·m** | **0.55 N·m** |

This assumes the keeper has no play: layers of PTFE tape under the flange set it at assembly
([build guide](docs/build_guide.md), step 2). The keeper, the disc and the pelvis passed their own finite-element
checks (fatigue / strength: keeper 2.1 / 5.2, disc 2.4 / 3.6, pelvis 2.4 / 5.1). The hip yaw turns ±12°, more than
twice what the gaits use.

## The reference robot

JX0 copies a friend's robot: a small biped printed in pastel green with **every joint a 12 V STS3215**, a faceted
body, an exposed neck servo under a soft rounded head, and flat blade arms that swing as it walks. It walks steadily,
takes a shove, and knocks over a bottle on the way. JX0 matches that:

| On the reference robot | On JX0 v0.4 |
|---|---|
| 12 V STS3215 in every joint | 17 × Feetech STS3215 12 V (Evelta lists it as ST3215-C018, dual shaft), all on one serial bus |
| leg servos held on both faces: caged servo bodies, wide angled U-brackets, cross-pattern horn screws | the same: every leg pitch and roll joint is a cage + U-bracket on the horn and the rear hub |
| short legs under a wide body, hip servos hidden under it | 62 mm thigh, 58 mm shin; a skirt on the torso hides the hip-yaw servos |
| chamfered foot plates | chamfered 124 × 70 mm soles with a 1 mm rubber pad |
| pastel green print | eSun PLA-Matte Mint Green for the body; green PETG for the leg parts, which carry every step |
| faceted torso, vents on top, seam below the shoulders | octagonal torso with chamfered vertical edges; lower shell + chest cap with chamfered top edges, vent slots and a speaker grille |
| black neck servo exposed under the head | neck STS3215 standing on the chest cap |
| soft rounded head with four holes | rounded head, narrower at the chin, four holes in a diamond (the microphone listens through them) |
| shoulder servo in a bracket outside the chest, flat tapered arm | shoulder STS3215 in a hood outside the chest, elbow STS3215 in a box below it, a flat 6 mm paddle blade |
| walks with the arms swinging, takes a shove | gaits verified with a 1.6× counter-swing; stays up through every push up to 0.96 N·s ([verification](results/verification.md)) |
| runs off a 12.6 V bench supply | 3S LiPo, or a 12.6 V bench supply on the same XT60 |

## Honest status

| | Status |
|---|---|
| SolidWorks CAD: 22 printed parts + all 17 servos in the assembly | **done**, every part rebuilt by script, one body each, no errors |
| Parts colliding, standing or in motion (every gait frame and action, 1,373 poses; every joint over its full range) | **none** |
| Servo sizing (every leg joint, 5 gaits + 8 static cases), 2.88 kg robot | **passes**; the tightest is hip roll with a 1.46× margin |
| Strength of every printed leg part, finite elements under the simulated loads | **passes**: fatigue safety factor 2.1 or more, strength 3.0 or more (PETG data ASSUMED) |
| Walking in simulation, on the CAD masses and a servo model | **14 of 14 gaits pass** with arm swing (forward 0.05 m/s, backward, turns, side-steps) |
| Walking when the real robot differs from the model (servo stiffness, latency, backlash, IMU noise, mass, friction, slope) | **138 of 140** random walks pass (latency up to 20 ms) and **all 140 stay up**; with 40 ms latency 123 pass, all 140 stay up |
| The whole robot program, an 8-action mission, random realistic errors | **24 of 24** completed without a fall |
| Pushes mid-walk (48 timings each) | stays up through **every** push up to 0.96 N·s; 90 % at 1.2 N·s, 44 % at 1.44 N·s |
| Robot program (voice, Claude brain, walking, gestures) | **written, unit-tested (21 tests) and run in simulation**; not yet on hardware |
| Parts list | ₹58,215; STS3215 price and stock checked 2026-10-04 ([8-page cost estimate](bom/JX0_cost_estimate.pdf)) |
| Physical robot | **not built yet**: this is what the funding is for |

All of it is in the **[verification report](results/verification.md)**: what was checked, what it found and fixed, and
the honest limits (`python jx0/verify/run_all.py` re-runs everything in about 45 minutes). Unverified until the robot
is built, and the first things to check: a test U-bracket on a servo (the rear hub's screw pattern is ASSUMED equal to
the horn's), the M2 screw fit in the printed holes, the servo stiffness setting and the I2S audio overlay. Battery life
is about 73 minutes of walking (CALCULATED: 1.45 A average for the servos and the Pi).

## What it can do

| Ask it… | It… |
|---|---|
| "Hi!" / any question | answers out loud in one to three sentences (Claude) |
| "Walk forward five steps" / "go back" / "step left" | plays the gait blocks verified in simulation, arms swinging, with IMU balance on the stance leg |
| "Turn around" | repeats 10° turn blocks until the IMU says it has turned far enough |
| "Wave at me" | raises an arm up in front and wags the blade |
| "Look left" / "yes or no?" | turns its head; bows for yes, shakes its head for no |

## JX0 at a glance

| | |
|---|---|
| Height, mass | 46.0 cm, 2.88 kg (CAD) |
| Joints | 17 Feetech STS3215 12 V serial bus servos: 6 per leg, shoulder pitch and elbow per arm, neck yaw |
| Brain | Raspberry Pi 4 (2 GB): gaits and balance at 100 Hz, MPU6050 IMU, Vosk speech recognition, Piper voice, Claude over Wi-Fi |
| Power | 3S 2200 mAh LiPo straight to the servo bus (12 V servos); a 5 V UBEC for the Pi; or a 12.6 V bench supply |
| Structure | 22 printed parts, 847 g: pelvis and leg parts in PETG, printed near-solid (554 g); body, head and arms in PLA (293 g) |

## What it costs

| Group | ₹ |
|---|---|
| Servos: 17 × STS3215 | 41,123 |
| Electronics: Pi 4, microSD, servo driver, button, wiring | 9,151 |
| Structure: PLA and PETG filament, screws, inserts, rubber, PTFE tape | 4,123 |
| Power: LiPo, charger, UBEC, switch, wire, alarm | 3,122 |
| Voice: microphone, amplifier, speaker | 569 |
| Sensors: IMU | 127 |
| **Total** | **58,215** |

Line by line with store links: [bom/jx0_bom.csv](bom/jx0_bom.csv). The 17 servos are 71 % of the cost. JX0 is
₹8,215 over the original ₹50,000 target because every joint is an STS3215, as on the reference robot. The walking
needs 2.0 N·m at the hip roll (with the 1.25–1.5× margins), which rules out MG996R-class hobby servos, and the serial
bus servos also report their position, which the calibration and the balance loop use.

## How it works, in plain words

- **Walking.** A planner (the same one designed for JX1) works out where the body's balance point must be at every
  instant for a given step length and speed, then computes the 12 leg joint angles 100 times a second. The arms
  counter-swing with the opposite leg, like the reference robot. Those trajectories were run on a physics model of this
  exact robot, with a model of how the servos really behave (they give a little under load and slow down when pushed
  hard). Only the gaits that passed are shipped in `software/jx0bot/gaits/`. On the robot, the IMU corrects the ankles
  and hips as it walks.
- **Talking.** A button, or saying "hey robot", starts listening. Vosk turns speech into text on the Pi itself. Claude
  writes a short spoken reply and can call the robot's actions as tools. Piper speaks the reply sentence by sentence
  through the speaker under the chest grille.
- **One bus.** All 17 servos are chained on one serial bus from a small driver board on the Pi's USB. There's no PWM
  wiring, and every joint reports its angle.

## Try it on your PC

No hardware needed. Install the packages, then talk to the simulated robot by typing:

```bash
pip install -r jx0/software/requirements-pc.txt
```

```bash
cd jx0/software && python -m jx0bot.main --sim --text
```

It needs an `ANTHROPIC_API_KEY`. Without one, you can still run these:
- `python jx0/sim/demo_jx0.py` renders the demo film.
- `python jx0/sim/walk_jx0.py` reruns every walking check.
- `python jx0/cad/preview.py` builds and renders the robot from the geometry, with no SolidWorks needed.
- `python jx0/verify/run_all.py` reruns the whole verification.

## How it was designed and checked

| Step | Tool | Result |
|---|---|---|
| Design point: sizes, masses, joint ranges | [design_point.yaml](design_point.yaml) | every value labelled VERIFIED / CALCULATED / ESTIMATED / ASSUMED |
| Servo sizing | [analysis/sizing.py](analysis/sizing.py) → [results/sizing.md](results/sizing.md) | peak ×1.5 ≤ stall, RMS ×1.3 ≤ rated, inside the torque-speed line: **all pass** |
| CAD | [cad/geometry.py](cad/geometry.py) → SolidWorks by script | 22 printed parts, assembly with all 17 servos, masses fed back into the design point |
| Walking | [sim/walk_jx0.py](sim/walk_jx0.py) → [results/walking.json](results/walking.json) | 14/14 gaits with arm swing at 100 Hz: tilt ≤ 1.4°, final position error ≤ 10 mm, servo peaks ≤ 55 % of stall |
| Collisions | [verify/verify_cad.py](verify/verify_cad.py) | 0 clashes in 741 part pairs and 1,373 moving poses; every joint limit inside its collision-free range |
| Robustness | [verify/robustness.py](verify/robustness.py) | 140/140 random-error walks stay up (139 pass); 24/24 whole-program missions; pushes up to 0.96 N·s: 100 % stay up |
| Joint strength | [verify/verify_strength.py](verify/verify_strength.py) | single-sided plates would crack (fatigue SF 0.18–0.51); U-brackets 4.7–8.0 |
| Leg parts, finite elements | [verify/verify_fea.py](verify/verify_fea.py) | every printed leg part: fatigue SF ≥ 2.1, strength SF ≥ 3.0 ([stress maps](results/images)) |
| Power and timing | [verify/verify_power.py](verify/verify_power.py) | 1.44 A walking (≈ 73 min per charge), 2.5 A peak; the 100 Hz loop uses ~2 of 10 ms on a Pi 4 |
| Software | [software/tests](software/tests/test_jx0bot.py) | 21 unit tests: servo protocol bytes vs the Feetech manual, config, gait files, kinematics vs the model, Claude tool loop |
| Whole robot program | [sim/demo_jx0.py](sim/demo_jx0.py) | every action runs on the simulated robot; it takes a hard side push and bumps a bottle out of its way |

| Gait | Speed | Distance plan → sim | Heading error | Max tilt | Peak servo load |
|---|---|---|---|---|---|
| forward (10 steps) | 0.050 m/s | 0.255 → 0.245 m | 0.0° | 1.4° | 54 % |
| forward slow | 0.050 m/s | 0.195 → 0.188 m | 0.0° | 1.4° | 54 % |
| backward | 0.033 m/s | 0.130 → 0.121 m | 0.0° | 1.4° | 54 % |
| turn left 70° / right 70° | — | — | −3.4° / +3.4° | 1.4° | 55 % |
| side-step left | — | 0.060 → 0.057 m | 0.0° | 1.3° | 54 % |

## Folder map

| Path | What |
|---|---|
| `design_point.yaml` | the numbers everything else reads |
| `analysis/` | servo sizing |
| `cad/` | geometry, SolidWorks build scripts, `preview.py`, `render_cad.py`, `parts/*.SLDPRT`, `JX0_Robot.SLDASM`, `stl/` for printing |
| `sim/` | MuJoCo model, walking checks, demo film |
| `verify/` | collisions, robustness, strength, finite elements, power and timing checks; `run_all.py` writes [results/verification.md](results/verification.md) |
| `software/jx0bot/` | the robot program (see [software_setup.md](docs/software_setup.md)) |
| `bom/` | parts list and the cost PDF |
| `docs/` | build guide, wiring, bring-up, software setup |
| `results/` | sizing, walking and verification results, images and films |

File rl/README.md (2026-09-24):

# JX1 — trainable model (MuJoCo · Isaac Lab · ROS 2)

Phase 3 of JX1: the CAD-derived robot as a **reinforcement-learning-ready model** with one policy format that runs in
MuJoCo, Isaac Lab and ROS 2. The walking task, its conventions and the deployment gains live in one file,
[`config/jx1_walk.yaml`](config/jx1_walk.yaml); every other piece reads it.

```text
 SolidWorks CAD ──► tools/sim/build_robot_description.py ──► simulation/mujoco/jx1.xml   ros2_ws/.../jx1.urdf(.xacro)
                                                                   │                          │
            rl/config/jx1_walk.yaml (joints, default pose,         ▼                          ▼
            PD gains, obs/action layout, rewards, DR, PPO)   rl/ (MuJoCo, CPU-batched)   simulation/isaac/isaaclab (Isaac Lab)
                                                                   │  train.py → export.py    │  scripts/train.py → export_policy.py
                                                                   ▼                          ▼
                                             policy bundle: policy.onnx + policy.pt + policy_io.yaml
                                                                   │
                        ┌──────────────────────────────────────────┼───────────────────────────────┐
                        ▼                                          ▼                               ▼
              rl/sim2sim.py (full CAD MuJoCo,         ros2_ws: jx1_policy node  ◄──►  jx1_sim (MuJoCo node) / Isaac Sim ROS 2
              500 Hz, mesh-hull collisions)           /jx1/joint_states /jx1/imu /cmd_vel → /jx1/joint_command (or ros2_control)
```

## What is where

| Path | Contents | Status |
|---|---|---|
| `rl/config/jx1_walk.yaml` | task definition: 12 policy joints, default pose, deployment PD gains, action scale 0.25, 47-D observation, gait clock, commands, rewards, domain randomisation, PPO | source of truth |
| `rl/jx1_rl/assets.py` | CAD MJCF → training model (capsules/boxes fitted to the CoACD hulls, collision groups, gains, sensors, `home` keyframe) | tested |
| `rl/jx1_rl/env.py` | batched MuJoCo environment on `mujoco.rollout` (C++ thread pool), rewards, DR, pushes, resets | tested, ~20k policy steps/s on 8–11 threads |
| `rl/jx1_rl/ppo.py`, `rl/train.py` | PPO (rsl_rl algorithm: asymmetric actor-critic, running normalisers, GAE, adaptive LR), GPU update, left/right mirror loss (`jx1_rl/symmetry.py`) | tested |
| `rl/export.py` | TorchScript + ONNX (normaliser baked in) + `policy_io.yaml`, checked against the checkpoint | tested |
| `rl/sim2sim.py` | exported policy on the **full CAD model** (mesh hulls, 500 Hz, no DR), 7 command scenarios; optional sensing/actuation delay; per scenario: tracking, torque/speed margins, foot lift-offs, self-contact between robot bodies | tested |
| `rl/envelope.py`, `rl/push_test.py`, `rl/latency_test.py`, `rl/power_test.py` | command envelope (vx × wz, vx × vy grids, incl. self-contact), push recovery (walking and standing), latency sensitivity, electrical power / battery current / actuator thermal load, all on the CAD model | tested |
| `rl/report.py`, `rl/compare_policies.py`, `rl/play.py` | `REPORT.md` policy card per bundle, side-by-side comparison, keyboard driving in the MuJoCo viewer | tested (viewer: headless path) |
| `rl/tests/test_rl.py` | quaternion maths vs MuJoCo, ankle-polygon projection (numpy/ROS/torch), env determinism, training-vs-deployment observation parity, latency, hub ramp, MuJoCo/Isaac `policy_io` parity, hardware protocol/bridge/IMU, rough terrain, GAE/normaliser, ros2_control xacro, mirror maps vs MuJoCo physics, stand-mode clock gating | 15/15 pass |
| `simulation/isaac/isaaclab/` | Isaac Lab tasks `Isaac-Velocity-{Flat,Rough}-JX1-v0` (+ `-Play`), same obs/actions/rewards/DR; rsl_rl config, train and export scripts, offline API check, Isaac Sim ROS 2 bridge | offline-checked against Isaac Lab 2.3.2 + rsl_rl 3.1.2 and the bridge and USD import against Isaac Sim 5.1 sources (89/89); **not run in Isaac Sim** |
| `ros2_ws/src/jx1_policy` | ONNX policy runner (no training code) + ROS 2 node (WAIT → RAMP → WALK, HOLD on stale state) | runner tested; node see below |
| `ros2_ws/src/jx1_sim` | MuJoCo ROS 2 node: `/clock`, `/jx1/joint_states`, `/jx1/imu`, `/jx1/odom`, TF; applies `/jx1/joint_command` | see below |
| `ros2_ws/src/jx1_bringup` | `mujoco_sim.launch.py`, `isaac_sim.launch.py`, `ros2_control.launch.py`, controllers | see below |
| `tools/sim/gen_ros2_control.py` | `jx1.ros2_control.xacro` (mock / topic_based_ros2_control), `jx1_system.urdf.xacro`, `controllers.yaml` | generated |
| `ros2_ws/src/jx1_hw` | Jetson ↔ CAN-hub bridge (firmware USB protocol, parallel-ankle IK/FK, motor gains), hub-firmware digital twin, `hardware.launch.py` | protocol + bridge tested; HIL run on the emulator |
| `rl/ros2_check.py`, `rl/hw_loop_check.py`, `rl/ros2_env/build_ws.py` | end-to-end checks over real ROS 2 (sim node / hardware bridge + emulated hubs), from the source tree or with `--launch` from a colcon install (`mujoco_sim.launch.py`, `ros2_control.launch.py`, `hardware.launch.py hil:=true`) | run on this machine (RoboStack Jazzy) |

## Trained policies (final CAD model, 33.61 kg)

Each bundle in `rl/policies/` has `policy.onnx`, `policy.pt`, `policy_io.yaml` and every check result, summarised in its
`REPORT.md`. A copy for ROS 2 lives in `ros2_ws/src/jx1_policy/policies/`. The **default is `jx1_walk_stand_v7`** for
the ROS 2 policy node, the launch files, the hardware launch, the Isaac Sim bridge and the rl tools
(`jx1_rl.DEFAULT_POLICY`); `jx1_walk_rough` was the default before it.

<!-- policies:start -->
| | `jx1_walk_flat` | `jx1_walk_rough` | `jx1_walk_sym_latency` | `jx1_walk_stand` | `jx1_walk_stand_sym` | `jx1_walk_stand_v7` |
|---|---|---|---|---|---|---|
| trained | walk_v2_final it 3000 | walk_v3_rough it 4000 | walk_v4_sym_latency it 5000 | walk_v5_stand it 4800 | walk_v6_stand_sym it 5600 | walk_v7_stand_free it 6400 |
| sim2sim flat | 7/7 upright; 0.5 m/s -> 0.50, turn 0.5 -> 0.47 rad/s, peak torque 90% | 8/8 upright; 0.5 m/s -> 0.52, turn 0.5 -> 0.49 rad/s, peak torque 81% | 7/7 upright; 0.5 m/s -> 0.51, turn 0.5 -> 0.49 rad/s, peak torque 70% | 8/8 upright; 0.5 m/s -> 0.52, turn 0.5 -> 0.46 rad/s, peak torque 83% | 8/8 upright; 0.5 m/s -> 0.49, turn 0.5 -> 0.42 rad/s, peak torque 74% | 8/8 upright; 0.5 m/s -> 0.48, turn 0.5 -> 0.50 rad/s, peak torque 84% |
| sim2sim rough | 7/7 upright; 0.5 m/s -> 0.50, turn 0.5 -> 0.47 rad/s, peak torque 95% | 8/8 upright; 0.5 m/s -> 0.53, turn 0.5 -> 0.49 rad/s, peak torque 79% | 7/7 upright; 0.5 m/s -> 0.52, turn 0.5 -> 0.50 rad/s, peak torque 72% | 8/8 upright; 0.5 m/s -> 0.53, turn 0.5 -> 0.47 rad/s, peak torque 86% | 8/8 upright; 0.5 m/s -> 0.50, turn 0.5 -> 0.43 rad/s, peak torque 76% | 8/8 upright; 0.5 m/s -> 0.48, turn 0.5 -> 0.50 rad/s, peak torque 81% |
| envelope flat | 99/130 tracked, 0 falls; fwd +1.13, back -0.59, yaw +0.85/-0.82 | 109/130 tracked, 0 falls; fwd +1.08, back -0.57, yaw +0.84/-0.86 | 102/130 tracked, 0 falls; fwd +1.05, back -0.58, yaw +0.89/-0.92 | 98/130 tracked, 0 falls; fwd +1.12, back -0.62, yaw +0.83/-0.86 | 117/130 tracked, 0 falls; fwd +1.09, back -0.59, yaw +0.78/-0.86 | 118/130 tracked, 0 falls; fwd +1.09, back -0.55, yaw +0.87/-0.88 |
| push (N s) | 12.7-21.6 (fwd 21.6, back 14.5, left 12.7, right 17.8) | 15.9-44.1 (fwd 32.8, back 35.6, left 15.9, right 44.1) | 11.7-39.8 (fwd 39.8, back 26.7, left 11.7, right 28.1) | 22.5-55.8 (fwd 36.1, back 38.4, left 22.5, right 55.8) | 29.5-57.7 (fwd 44.1, back 46.4, left 29.5, right 57.7) | 29.1-60.0 (fwd 53.4, back 42.2, left 29.1, right 60.0) |
| HIL (hub twin) | fwd 95% of 0.3 m/s, turn 74% of 0.3 rad/s | fwd 95% of 0.3 m/s, turn 88% of 0.3 rad/s | fwd 95% of 0.3 m/s, turn 72% of 0.3 rad/s | fwd 97% of 0.3 m/s, turn 75% of 0.3 rad/s | fwd 88% of 0.3 m/s, turn 71% of 0.3 rad/s | fwd 84% of 0.3 m/s, turn 92% of 0.3 rad/s |
| turn 0.3 tracking | 85% (no delay), 70% (20 + 10 ms) | 101% (no delay), 94% (20 + 10 ms) | 84% (no delay), 74% (20 + 10 ms) | 83% (no delay), 75% (20 + 10 ms) | 80% (no delay), 73% (20 + 10 ms) | 102% (no delay), 90% (20 + 10 ms) |
| self-contact, envelope flat | - | 3/130 commands (1 in the trained range): left_shin_link|right_shin_link (2), left_foot_link|right_foot_link (1) | - | 0/130 commands (0 in the trained range): none | 0/130 commands (0 in the trained range): none | 5/130 commands (0 in the trained range): left_shin_link|right_shin_link (3), left_shin_link|right_foot_link (1), left_foot_link|right_foot_link (2) |
| self-contact, envelope rough | - | 3/130 commands (1 in the trained range): left_shin_link|right_shin_link (2), left_foot_link|right_foot_link (1) | - | 0/130 commands (0 in the trained range): none | 0/130 commands (0 in the trained range): none | 4/130 commands (1 in the trained range): left_shin_link|right_shin_link (2), left_foot_link|right_foot_link (2) |
| envelope rough | - | 108/130 tracked, 0 falls; fwd +1.09, back -0.56, yaw +0.84/-0.86 | 98/130 tracked, 0 falls; fwd +1.07, back -0.58, yaw +0.89/-0.93 | 94/130 tracked, 0 falls; fwd +1.13, back -0.61, yaw +0.83/-0.86 | 117/130 tracked, 0 falls; fwd +1.11, back -0.59, yaw +0.78/-0.87 | 119/130 tracked, 0 falls; fwd +1.10, back -0.56, yaw +0.87/-0.88 |
| stand -> walk 0.5 -> stand | - | upright, 2.50 foot lift-offs/s in the last 2 s | - | upright, 0.00 foot lift-offs/s in the last 2 s | upright, 0.00 foot lift-offs/s in the last 2 s | upright, 0.00 foot lift-offs/s in the last 2 s |
| stand (zero command) | - | 2.51 foot lift-offs/s, drift 0.05 m, 163 W | - | 0.00 foot lift-offs/s, drift 0.00 m, 79 W | 0.00 foot lift-offs/s, drift 0.00 m, 79 W | 0.00 foot lift-offs/s, drift 0.00 m, 73 W |
| power 0.5 / 0.8 m/s | - | 283 W / 368 W | - | 313 W / 382 W | 284 W / 363 W | 274 W / 347 W |
| push standing (N s) | - | 19.2-36.1 | - | 27.7-47.8 | 11.7-51.6 | 26.2-55.3 |
| HIL 0.8 m/s | - | 0.70 m/s, upright | - | 0.70 m/s, upright | 0.70 m/s, upright | 0.68 m/s, upright |
<!-- policies:end -->

- `jx1_walk_flat`: 1500 iterations on the placeholder model, then 1500 on the final CAD model (flat floor).
- `jx1_walk_rough` (default until `jx1_walk_stand_v7`): `jx1_walk_flat` fine-tuned for 1000 iterations on the rough
  heightfield. It is better on flat ground too. It leaves more torque headroom (peaks at 71–73 % against the hubs' 80 % cap), takes about twice the push
  impulse, has no yaw drift and tolerates latency.
- `jx1_walk_sym_latency` (experiment): `jx1_walk_rough` + 1000 iterations with the left/right mirror loss, 0–15 ms
  sensing / 0–10 ms actuation latency and half the entropy bonus. It came out slightly worse: 102 vs 109 commands
  tracked, 72 vs 88 % turn tracking through the HIL chain, 11.7 N·s vs 15.9 N·s worst push, and back to 84 %
  tracking of 0.3 rad/s turns. The rough policy had already lost the yaw drift and tolerates 40 ms + 20 ms latency, so
  it stays the default. Kept for reference; not installed with the ROS 2 package.
- `jx1_walk_stand` (experiment, OI-27): `jx1_walk_rough` + 800 iterations with the stand mode (clock features 0 below a
  command norm of 0.1, both feet down, no swing target) and 20 % zero commands. It really stands: 0 foot lift-offs/s
  instead of 2.5, 79 W instead of 163 W (4.7 h instead of 2.3 h on the pack), and it settles within 2 s after walking.
  It also takes larger pushes (22.5–55.8 N·s walking, 27.7–47.8 N·s standing) and has no leg self-contact over the
  envelope. But it tracks leftward side-steps and slow turns worse: 98 vs 109 commands, 0.3 rad/s turns at 83 % vs
  101 %, HIL turn 75 % vs 88 %. So `jx1_walk_rough` stays the default until a stand-mode policy matches its tracking.
- `jx1_walk_stand_sym` (experiment): `jx1_walk_stand` + 800 iterations with 10 % zero commands and a mild mirror loss
  (0.2). It keeps the stand mode (79 W, settles after walking) and has the widest envelope so far: 117/130 on flat and on
  rough ground, symmetric side-steps (±0.36 m/s), 29.5–57.7 N·s walking pushes and no self-contact. Its weak points:
  slow turns at 80 %, HIL 88 % forward / 71 % turn, −0.03 rad/s yaw drift while walking, and only 11.7 N·s forward push
  while standing, because the both-feet-down contact reward penalised recovery steps. `walk_v7` drops that stand-mode
  contact target (`gait.stand_contact_reward: none`) and weights yaw tracking 0.8.
- **`jx1_walk_stand_v7` (default)**: `jx1_walk_stand_sym` + 800 iterations without a stand-mode contact target
  (`gait.stand_contact_reward: none`, so it may step to recover) and yaw tracking weighted 0.8. Against `jx1_walk_rough`:
  - Standing: it stands still at 73 W (5.1 h on the pack, vs 163 W / 2.3 h) and settles after walking.
  - Envelope: widest so far, 118/130 flat and 119/130 rough, with side-steps ±0.39 m/s and turns ±0.87 rad/s.
  - Pushes: 29–60 N·s walking and 26–55 N·s standing, against 16–44 and 19–36.
  - Turns: 0.3 rad/s tracked at 102 % (90 % with 20 + 10 ms delay); HIL turn 92 % vs 88 %.
  - Power: walking takes less (274 / 347 W at 0.5 / 0.8 m/s).
  - Slow forward walking undershoots: HIL 84 % of 0.3 m/s vs 95 %, ROS 2 93 % of 0.4 m/s.
  - At 0.8 m/s the ankle pitch peaks at 82 % of the linkage capability (ankle motor 34 N·m without the hub cap). Through
    the hub's 80 % caps it still walks 0.68 m/s upright.
  - Self-contact: shins and feet graze (≤ 0.8 mm hull overlap) in 4–5 of 130 commands, mostly beyond the trained
    side-step range.
- Every bundle's `policy_io.yaml` carries the hip-yaw toe-out coupling (`hip_yaw_toe_out_max_rad`, OI-24), applied by
  every runner. The learned gaits never reach it (22.9° max toe-out sum against the 40° limit).
- Table generated by `rl/compare_policies.py <bundles>`. "HIL" is the hardware-in-the-loop run through `hw_node` and the
  hub-firmware twin.

## Train in MuJoCo (this machine: Windows, RTX 3050 6 GB, i5-13420H)

```bash
py -3.13 -m venv rl/.venv
rl/.venv/Scripts/python -m pip install torch==2.14.0 --index-url https://download.pytorch.org/whl/cu126
rl/.venv/Scripts/python -m pip install -r rl/requirements.txt
rl/.venv/Scripts/python rl/tests/test_rl.py
rl/.venv/Scripts/python rl/train.py --num-envs 1024 --iterations 3000 --run my_run        # rl/runs/my_run/
rl/.venv/Scripts/python rl/export.py --checkpoint rl/runs/my_run/model_latest.pt           # rl/policies/jx1_walk_flat/
rl/.venv/Scripts/python rl/sim2sim.py                                                      # full CAD model check + GIF
```

Resume or fine-tune on a regenerated CAD model with `--resume rl/runs/<run>/model_latest.pt`.

**Numerical note (MEASURED):** with the Newton solver's line search capped at 10 iterations the model injected energy
after falls (robots launched to hundreds of metres, 5/6 seeds); `ls_iterations >= 20` fixed it with no speed cost, so
the task uses 50/50.

### Rough ground

`rl/config/jx1_walk_rough.yaml` inherits the flat task (`base:` key) and replaces the floor with a 16 m heightfield of
2 m tiles: flat, ±2 cm uneven floor, domes/bowls up to 8°, and ±2 cm step strips (thresholds, cable covers). Every
non-step tile returns to zero at its edges, so the only discontinuities are the step edges (≤ 4 cm). Robots spawn over
the whole map; base height, foot clearance and the fall check are measured above the local ground; leaving the map ends
the episode without penalty. The observation stays blind (same 47-D vector), so the rough policy fine-tunes from the flat
one and deploys through the same `policy_io.yaml`, ROS 2 node and hardware bridge.

```bash
rl/.venv/Scripts/python rl/train.py --config rl/config/jx1_walk_rough.yaml --resume rl/runs/<flat run>/model_latest.pt --iterations <n>
rl/.venv/Scripts/python rl/sim2sim.py --policy rl/policies/jx1_walk_rough --terrain rl/config/jx1_walk_rough.yaml
```

### Robustness checks

- `rl/sim2sim.py [--terrain ...]`: 7 command scenarios on the full CAD model (mesh hulls, 500 Hz, hub target ramp);
  velocity tracking, tilt, peak torque / effort limit and peak joint speed / speed limit per scenario.
- `rl/push_test.py`: 0.1 s torso force pulse while walking at 0.5 m/s, bisection of the largest survived impulse per
  direction (same method as `simulation/mujoco/push_jx1.py` for the model-based controller). Interim policy on the
  placeholder-torso model: 11.7–23.4 N·s, vs 6.6–7.8 N·s for the fixed-footstep ZMP controller.
- `rl/envelope.py`: constant-command walks over a vx × wz and a vx × vy grid, from inside the training ranges to beyond
  them. For each command it records falls, tracking and torque margin, and writes `envelope.json` and `envelope.png`. The
  whole grid takes about a minute on 4 processes.
- `rl/power_test.py`: battery power, current and actuator RMS current vs rated for standing and walking, with the
  electrical model of `calculations/run_power_budget.py` (ankle motors through the linkage), plus foot lift-offs.
- Stand and self-contact metrics (every `sim2sim.py` / `envelope.py` rollout): foot lift-offs per second, swing fraction
  and base travel (stepping in place, OI-27), and every contact between two robot bodies on the CAD hulls (leg-leg OI-7,
  hip-yaw brackets OI-24, arm-thigh OI-18). The detector reports the hip-yaw bracket contact at 22° toe-out per hip, as
  the OI-24 sweep found.
- `rl/report.py`: gathers every check of a bundle (training curves, sim-to-sim, envelope, pushes, power, ROS 2, HIL)
  into the bundle's `REPORT.md`.

## Train in Isaac Lab (offline-checked, not yet run in Isaac Sim)

```bash
cd <IsaacLab> && ./isaaclab.sh -p -m pip install -e <repo>/simulation/isaac/isaaclab
./isaaclab.sh -p <repo>/simulation/isaac/isaaclab/scripts/train.py --task Isaac-Velocity-Flat-JX1-v0 --headless --num_envs 4096
./isaaclab.sh -p <repo>/simulation/isaac/isaaclab/scripts/train.py --task Isaac-Velocity-Rough-JX1-v0 --headless   # terrain generator
# deployment bundle straight from the checkpoint, on any machine with rl/.venv (no Isaac Sim needed):
rl/.venv/Scripts/python simulation/isaac/isaaclab/scripts/export_offline.py --checkpoint <log>/model_2999.pt --out rl/policies/jx1_walk_flat_isaac
rl/.venv/Scripts/python rl/sim2sim.py --policy rl/policies/jx1_walk_flat_isaac     # the Isaac-trained policy on the MuJoCo CAD model
```

Isaac Sim does not fit the design machine (RTX 3050 6 GB, 24 GB RAM, full system drive), so these tasks have not been
run. They are **checked offline against the Isaac Lab 2.3.2 sources and rsl_rl 3.1.2**:

```bash
git clone --depth 1 --branch v2.3.2 https://github.com/isaac-sim/IsaacLab.git <dir>/IsaacLab-2.3.2
rl/.venv/Scripts/python -m pip download rsl-rl-lib==3.1.2 --no-deps -d <dir>      # unzip the wheel to <dir>/rsl_rl_src
rl/.venv/Scripts/python simulation/isaac/isaaclab/scripts/offline_check.py --isaaclab <dir>/IsaacLab-2.3.2 --rsl-rl <dir>/rsl_rl_src
```

`offline_check.py` mocks the Omniverse modules (as Isaac Lab's own docs build does) and imports the real Isaac Lab code.
It checks all four tasks (89/89 pass, report in
[`offline_check.json`](../simulation/isaac/isaaclab/offline_check.json)):
- Every env and runner config instantiates, and `validate()` passes.
- Every manager term resolves as Isaac Lab resolves it at start-up (signature, scene entities against the robot the URDF
  importer builds).
- Every observation, reward and termination term runs on a fake scene whose attribute names are checked against the
  real data classes.
- Policy and critic observations equal the MuJoCo task's (47 and 55 values).
- The action term produces the MuJoCo targets on every physics substep: clamp, ankle polygon, hub ramp, delay, reset.
- Actuators cover all 23 joints with the task gains.
- The scripts' imports and keyword arguments match the library signatures.
- The offline exporter matches `rsl_rl`'s `ActorCritic.act_inference`.
- With `--isaacsim <sparse clone of isaac-sim/IsaacSim v5.1.0>`, it checks the Isaac Sim ROS 2 bridge
  (`scripts/ros2_bridge.py`). Every OmniGraph node type must exist as an `.ogn` definition, every connected or set
  attribute must exist with matching types, "target" inputs must be set as path lists, and every Isaac Sim Python call
  must match its source signature. `simulation/isaac/import_jx1.py` (URDF → USD) is checked the same way against the URDF
  importer: its import-config fields, command names and arguments.

What the check found and what was fixed:
- **Deployment bug:** under rsl_rl ≥ 3 (Isaac Lab ≥ 2.3) the observation normaliser moved into the policy. The export
  script therefore wrote an ONNX without it, and the deployed policy would have received raw observations.
  `export_policy.py` is fixed. `export_offline.py` reads both checkpoint layouts.
- **Runner config:** `obs_groups` is now set, so the critic gets the privileged group. The deprecated
  `empirical_normalization` is dropped on ≥ 2.3. Actions are clipped at ±100, as in MuJoCo.
- **Action term:** after a reset the ramp started from the previous episode's last target. It now starts from the
  default pose, and a 0–1 substep transport delay was added, both as in `env.py`.
- **Critic:** it lacked the MuJoCo privileged terms (base height, foot contact, sole heights). It now matches the 55 values.
- **Rough task:** the base-height reward was off, and the fall check and swing height used world z. They are now
  measured from the ground under the robot, via a pelvis height scanner that only the critic and rewards see.
- **Randomisation:** friction pairs are consistent, armature is randomised, and gains are randomised on all joints,
  as in MuJoCo.
- **Symmetry:** the MuJoCo trainer's left/right mirror loss (`ppo.symmetry_coef`, `rl/jx1_rl/symmetry.py`) is wired
  into rsl_rl's `RslRlSymmetryCfg`. It uses the same mirror maps, loaded from the repository.
- **Isaac Sim bridge:** the joint-state publisher and the IMU reader had their "target" inputs set with strings.
  Isaac Sim ≥ 4.5 needs `[usdrt.Sdf.Path(...)]` there, so both nodes would have published nothing. The robot also
  spawned at the origin with the importer's drive gains. It now stands at the default pose, 1 cm above the floor, and
  gets the policy's deployment PD gains. The ground has the MuJoCo floor friction (μ 1, no restitution; the default
  plane bounces with 0.8). `/jx1/odom` is published for the ROS 2 checks.

- **Sensing latency:** Isaac Lab observes only the latest physics state. The action term now snapshots the robot state
  at every physics substep, and the `delayed_*` observation terms serve each env its randomised 0–15 ms old state,
  indexed like MuJoCo's `obs_src` (checked substep by substep).

Still different from MuJoCo:
- No joint friction torque: PhysX joint friction is a coefficient, while MuJoCo uses `frictionloss`.
- PhysX contacts instead of MuJoCo soft contacts. Running an Isaac-trained bundle through `rl/sim2sim.py` on the CAD model
  measures exactly this gap.

Asset: `simulation/isaac/jx1.usd` from `simulation/isaac/import_jx1.py` if it exists, otherwise the URDF with absolute
mesh URIs.

## Run on ROS 2

```bash
export JX1_REPO=<repo>
colcon build --packages-select jx1_description jx1_policy jx1_sim jx1_bringup && source install/setup.bash
pip install mujoco==3.14.0 onnxruntime
ros2 launch jx1_bringup mujoco_sim.launch.py viewer:=true         # MuJoCo + policy (direct /jx1/joint_command)
ros2 run teleop_twist_keyboard teleop_twist_keyboard              # /cmd_vel
ros2 launch jx1_bringup ros2_control.launch.py                    # same through ros2_control (topic_based_ros2_control)
ros2 launch jx1_bringup isaac_sim.launch.py                       # with simulation/isaac/isaaclab/scripts/ros2_bridge.py running
```

**Verified on the design machine (Windows 11, no system ROS):** ROS 2 Jazzy from RoboStack in a pixi environment
([`ros2_env/pixi.toml`](ros2_env/pixi.toml) + lock file), then the end-to-end check, which starts `jx1_sim` and
`jx1_policy` as separate ROS 2 processes, drives `/cmd_vel` and measures the walk from `/jx1/odom`:

```bash
pixi install --manifest-path rl/ros2_env/pixi.toml
pixi run --manifest-path rl/ros2_env/pixi.toml python rl/ros2_check.py --policy rl/policies/jx1_walk_flat
```

The packaged path is verified the same way. `rl/ros2_env/build_ws.py` runs `colcon build` on `ros2_ws/src` into a
workspace outside the repository. `ros2_check.py --launch` then starts everything with
`ros2 launch jx1_bringup mujoco_sim.launch.py` from that install space: the MuJoCo node, `robot_state_publisher` on the
xacro description, and the policy node. It drives the robot and writes `ros2_launch_check.json`.

```bash
pixi run --manifest-path rl/ros2_env/pixi.toml python rl/ros2_env/build_ws.py --ws <ws>
pixi run --manifest-path rl/ros2_env/pixi.toml python rl/ros2_check.py --policy rl/policies/jx1_walk_flat --launch <ws>/install
```

`jx1_bringup` is an ament_python package, so it builds without a C++ toolchain. `jx1_description` is ament_cmake and
only installs directories. On Windows without MSVC, `build_ws.py` replicates that install rule. On the Jetson or Ubuntu,
plain `colcon build` builds all five packages.

Topics (sim and hardware alike): `/jx1/joint_states` (JointState, all actuated joints), `/jx1/imu` (pelvis IMU),
`/cmd_vel` (vx, vy, wz) → `/jx1/joint_command` (JointState position targets). PD gains are applied downstream (MuJoCo
position actuators, PhysX drives, RobStride MIT mode) from `policy_io.yaml` → `pd_gains`.

## Real robot: hardware bridge and hardware-in-the-loop (`ros2_ws/src/jx1_hw`)

`hw_node` runs on the Jetson: `/jx1/joint_command` (joint space) → the two Teensy 4.1 CAN hubs over USB serial, in the
byte format of `firmware/hub/jx1_hub/jx1_hub.ino` (CRC-16/MODBUS frames, hub joint order/signs/limits generated from the
firmware configs into `config/hw.yaml`), and hub feedback → `/jx1/joint_states`. The ankle is driven as its two crank
motors: closed-form IK (identical to `calculations/jx1calc/ankle.py`), Newton FK for the feedback, J⁻¹ velocities,
Jᵀ torques. The hubs start in DAMPING; `ros2 service call /jx1/hw/run std_srvs/srv/Trigger` enables them (robot on the
gantry), `/jx1/hw/damp` goes back.

`fake_hub` is a digital twin of the hub firmware on the MuJoCo CAD model: the same protocol over TCP, the RobStride MIT
law at the 500 Hz bus rate with soft limits, the hub torque caps, the 20 ms target ramp, DAMPING/RUN and the host
watchdog, the push-rod ankle, and a bring-up gantry. `rl/hw_loop_check.py` runs policy → hw_node → "serial" → emulated
hubs → physics → back as separate ROS 2 processes and walks the robot over `/cmd_vel`:

```bash
pixi run --manifest-path rl/ros2_env/pixi.toml python rl/hw_loop_check.py --policy rl/policies/jx1_walk_flat
ros2 launch jx1_hw hardware.launch.py hil:=true            # the same chain from a launch file
ros2 launch jx1_hw hardware.launch.py port_a:=/dev/ttyACM0 port_b:=/dev/ttyACM1   # the real robot (+ IMU driver on /jx1/imu)
```

**What the hardware-in-the-loop run changed in training (MEASURED on the emulator, then modelled):**
- the hubs ramp each 50 Hz host target over the next 20 ms (first-order hold, ≈10 ms effective lag): now reproduced in
  the training environment, `sim2sim.py`, the `jx1_sim` node and the Isaac Lab action term;
- the two ankle motors run independent MIT loops, so the realisable joint-space roll/pitch stiffness ratio is fixed by the
  linkage (1.27): the task's ankle gains are now the realisable pair 51.2 / 64.8 N·m/rad (motor kp 40, kd 1.5);
- torques above 85 % of the actuator peak are penalised (the hubs cap at 80 %);
- the final flat policy tracked a 0.3 rad/s turn at 62 % through the chain vs 85 % in MuJoCo. `sim2sim.py` with added
  delay (`rl/latency_test.py`) reproduces that at about 30 ms of sensing plus 10 ms of actuation latency. Two fixes:
  - `hw_node` sent hub frames on its own 50 Hz timer, which added a random 0–20 ms delay after each policy output. It
    now forwards every command at once, which alone gave 73 % turn and 95 % forward tracking;
  - `walk_v4` then trained with 0–15 ms sensing and 0–10 ms actuation latency and came out worse
    (`jx1_walk_sym_latency`), while `jx1_walk_rough`, trained with 0–5 ms each, still tracks 0.3 rad/s turns at 89 % under
    40 ms + 20 ms added delay, so the task randomises 0–5 ms each;
- at zero command the free policy drifted −0.03 rad/s in yaw (+0.3 rad/s turns at 85 %, −0.3 at 109 %), although the
  robot is symmetric to 0.2 mm. PPO has a left/right mirror loss (`ppo.symmetry_coef`, mirror maps checked against
  MuJoCo physics); it is off by default because the rough fine-tune had already removed the drift and the mirrored
  `walk_v4` was worse.

## Conventions (policy_io.yaml)

- **Action**: 12 leg joints (left hip yaw, roll, pitch, knee, ankle pitch, roll; then right), `target = clip(default +
  0.25 * action, limits)`; ankle (pitch, roll) targets projected into the SolidWorks collision-free polygon
  (`joint_map.yaml` → `coupled_limits`). Waist, arms and neck hold the default walking posture.
- **Observation (47)**: body angular velocity × 0.25, projected gravity, command × (2, 2, 0.25), joint position −
  default, joint velocity × 0.05, last action, sin/cos of the 0.8 s gait clock (phase starts when walking starts).
  **Stand mode** (`gait.stand_command_threshold`, 0.1): below that command norm the clock features are 0, and in
  training the contact reward wants both feet down with no swing-height target (OI-27). Every runner (training env,
  `sim2sim.py`, the ROS 2 runner, Isaac Lab) applies the same rule; bundles without the key run the clock always.
- **Control**: 50 Hz policy; trained with 200 Hz physics (MuJoCo) — sim-to-sim runs the CAD model at 500 Hz.
- The parallel ankle is abstracted as serial pitch/roll joints with the linkage's capability limits (46/51 N·m);
  converting ankle targets to the two ankle motors is done by the hub (`calculations/jx1calc/ankle.py`).

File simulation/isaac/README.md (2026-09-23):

# JX1 in NVIDIA Isaac Sim / Isaac Lab

Isaac Sim is not installed on the design machine, so the USD has **not** been generated or tested here (UNVERIFIED).
The asset path is the CAD-derived URDF, which Isaac's URDF importer converts to USD:

1. Build the ROS 2 package or copy `ros2_ws/src/jx1_description` (URDF + `meshes/`).
2. Isaac Sim 4.x/5.x → *File → Import → URDF* with `import_config.yaml` settings, or run
   `./python.sh simulation/isaac/import_jx1.py` from the Isaac Sim directory.
3. Isaac Lab: point an `ArticulationCfg` at the generated `jx1.usd`; actuator limits come from `import_config.yaml`
   (effort/velocity per joint are already in the URDF `<limit>` tags).

The parallel ankle is modelled as serial pitch → roll joints (as Unitree G1 does in `unitree_rl_gym`); motor-space
conversion uses `calculations/jx1calc/ankle.py`.

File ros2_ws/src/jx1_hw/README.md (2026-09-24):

# jx1_hw: JX1 on the real robot

The Jetson runs four processes:
- `hw_node`: joint space ↔ the two Teensy 4.1 CAN hubs over USB serial.
- `imu_node`: BNO085 → `/jx1/imu`.
- `policy_node`: from `jx1_policy`.
- `robot_state_publisher`.

The hubs close the RobStride MIT loops at 500 Hz. The policy sends joint targets at 50 Hz. The hubs ramp each target
over the next 20 ms and apply the PD gains from `policy_io.yaml`. `hw_node` forwards each policy command to the hubs as
soon as it arrives. It used to send on its own 50 Hz timer, which added a random 0–20 ms delay. In the
hardware-in-the-loop run, removing that delay raised forward tracking at 0.3 m/s from 82 % to 93 % and turn tracking
from 62 % to 73 %.

**Status.** The following are verified without hardware:
- The byte protocol is checked against the firmware headers (CRC-16/MODBUS test).
- The parallel-ankle IK/FK/Jacobians round-trip (test).
- The whole chain runs against a digital twin of the hub firmware on the CAD model, both from Python and via
  `ros2 launch jx1_hw hardware.launch.py hil:=true` (`rl/hw_loop_check.py [--launch]`).

`imu_node` is **not verified**. It was written against the Adafruit BNO08x driver API and never run on a chip.

## 1. Jetson setup

The stack is tested with ROS 2 Jazzy (RoboStack) and uses only standard rclpy, launch and ros2_control APIs. JetPack 6
(Ubuntu 22.04) ships ROS 2 Humble, which these packages should also run on; that is untested.

```bash
sudo apt install ros-$ROS_DISTRO-robot-state-publisher ros-$ROS_DISTRO-xacro ros-$ROS_DISTRO-teleop-twist-keyboard
pip install onnxruntime pyserial pyyaml numpy adafruit-circuitpython-bno08x adafruit-blinka
cd ros2_ws && colcon build && source install/setup.bash
```

Give the hubs stable device names. A Teensy's USB serial is VID `16c0`, PID `0483`, and each board has its own serial
number (read it with `udevadm info /dev/ttyACM0 | grep SERIAL`). In `/etc/udev/rules.d/99-jx1.rules`:

```text
SUBSYSTEM=="tty", ATTRS{idVendor}=="16c0", ATTRS{idProduct}=="0483", ATTRS{serial}=="<hub A serial>", SYMLINK+="jx1_hub_a"
SUBSYSTEM=="tty", ATTRS{idVendor}=="16c0", ATTRS{idProduct}=="0483", ATTRS{serial}=="<hub B serial>", SYMLINK+="jx1_hub_b"
```

Hub A carries the left leg, the left arm and the waist, and hub B the right leg and the right arm. The neck servos
are not on the hubs. See `config/hw.yaml`, generated from the firmware configs by `scripts/gen_config.py`. The BNO085 goes on I2C bus 7 of the 40-pin header at
address 0x4A. `mount_rpy_deg` rotates the chip axes into the pelvis frame (x forward, y left, z up).

## 2. Before the first RUN

1. **Motor zeros.** `zero` in `config/hw.yaml` must be the motor reading at joint angle 0 (the URDF pose). Set each
   RobStride's mechanical zero in the calibration pose, or measure the offsets and put them in the firmware config.
   Then regenerate `hw.yaml`.
2. **Directions.** Launch the stack below. The hubs stay in DAMPING (kd only). Move every joint by hand and watch the
   model in RViz (`robot_state_publisher` on `/jx1/joint_states`). The model must follow your hand. If a joint mirrors,
   fix its `sign`.
3. **IMU.** Tilt the pelvis forward and check `/jx1/imu`: the orientation pitches nose-down and the angular velocity
   y is positive. Correct `mount_rpy_deg` if not.
4. **Ankles.** Pitch and roll are driven through the two crank motors (`jx1_hw/ankle.py`). With the foot moved by
   hand, `/jx1/joint_states` must show pitch and roll, never motor angles.

## 3. Bring-up sequence (robot in the gantry, E-stop in hand)

```bash
ros2 launch jx1_hw hardware.launch.py port_a:=/dev/jx1_hub_a port_b:=/dev/jx1_hub_b [policy_dir:=<bundle>]
ros2 topic echo /jx1/hw/status          # both hubs present, mode 1 (DAMPING), no fault, no E-stop
ros2 topic echo /jx1/policy_state       # WAIT -> RAMP -> WALK once joint states and IMU are fresh
ros2 service call /jx1/hw/run std_srvs/srv/Trigger     # hubs track the policy targets (mode 2)
```

1. Enable RUN with the feet just touching the floor. At zero command the policy balances in place.
2. Lower the gantry until the feet carry the weight. Keep slack in the rope, not tension.
3. Drive gently with `ros2 run teleop_twist_keyboard teleop_twist_keyboard`. The node clips commands to 0.8 m/s,
   0.3 m/s and 0.6 rad/s (parameter `max_cmd`).
4. Stop with `ros2 service call /jx1/hw/damp std_srvs/srv/Trigger` or the E-stop.

## 4. What protects the robot

| layer | behaviour |
|---|---|
| E-stop | hardware line into both hubs; RUN is refused while it is pressed |
| hub watchdog | no host frame for 50 ms → DAMPING |
| hub limits | targets clamped to the joint limits minus a soft margin; the total MIT torque (PD + feedforward) capped at 80 % of the motor peak: the motor runs the PD law itself, so the hub moves the position target to keep the torque predicted from the latest feedback within the cap; temperature derating of the cap |
| fall guard (`hw_node`) | pelvis tilt above 50° (`fall_tilt_deg`) latches DAMPING until the next `/jx1/hw/run` |
| policy node | holds the measured pose and drops to WAIT when joint states or the IMU are older than 0.1 s |

## 5. Rehearse in simulation first

```bash
pixi run --manifest-path rl/ros2_env/pixi.toml python rl/ros2_env/build_ws.py --ws <ws>
pixi run --manifest-path rl/ros2_env/pixi.toml python rl/hw_loop_check.py --policy rl/policies/jx1_walk_flat --launch <ws>/install
```

This runs the same launch file with `hil:=true`, and the hub-firmware twin replaces the hubs. The script follows the
procedure above: DAMPING, then WALK, then `/jx1/hw/run`, then gantry release and a `/cmd_vel` scenario. The measured
tracking through this chain is lower than in plain MuJoCo because of latency. The policy card of each bundle
(`REPORT.md`) has the numbers.

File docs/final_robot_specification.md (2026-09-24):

# JX1 — FINAL ROBOT SPECIFICATION

Generated by `tools/gen_final_spec.py` from the evidence files (design point v0.3). Labels: VERIFIED / MEASURED / CALCULATED / ESTIMATED / ASSUMED / UNVERIFIED. Nothing has been built or physically tested.

```text
JX1 FINAL ROBOT SPECIFICATION
Height (zero pose, CAD)        : 1.230 m  [CALCULATED]
Mass (CAD, all components)     : 33.61 kg  [ESTIMATED: CAD volumes x documented densities, datasheet actuator masses; upper body CAD]
Degrees of freedom             : 23 (legs 12, waist 1, arms 8, neck 2)
Leg                            : thigh 0.27 m, shin 0.3 m, ankle-sole 0.05 m, hip spacing 0.2 m
Foot                           : 0.21 x 0.095 m
Leg kinematics                 : hip yaw-roll-pitch (intersecting), knee pitch, 2-motor parallel ankle (pitch/roll)

Actuators (joint: model, peak / rated torque, requirement peak)
  hip_yaw       : RobStride RS06     36 /   11 N m   need 55.5 N m (-35 %)
  hip_roll      : RobStride RS03     60 /   20 N m   need 64.6 N m (-7 %)
  hip_pitch     : RobStride RS04    120 /   40 N m   need 119.9 N m (+0 %)
  knee          : RobStride RS04    120 /   40 N m   need 91.3 N m (+31 %)
  ankle_motor   : RobStride RS06     36 /   11 N m   need 39.1 N m (-8 %)
  waist          : RobStride RS06     36 / 11 N m
  shoulder p/r   : RobStride RS02     17 / 6 N m ; shoulder yaw, elbow: RobStride RS00 14 / 5 N m ; neck: Waveshare ST3215 x2
  requirement source: calculations/results/iter2_C_cad_masses/requirements.yaml (policy: peak = max(1.5 x dynamic, 1.25 x static))
  per scenario (1.5 x dynamic peak vs actuator peak): walk_slow_0.30ms: margins met
                                                      walk_nominal_0.52ms: margins met
                                                      walk_fast_0.79ms: hip_yaw 37.0 N m x 1.5 = 55.5 > 36 N m; hip_roll 43.1 N m x 1.5 = 64.6 > 60 N m
                                                      turn_15deg_per_step: margins met
                                                      squat: margins met
  static worst case (edge-of-foot CoP): ankle motor 31.2 N m raw = 1.15x margin (policy 1.25x)

Structure (FEA: actuator-capped GRF samples + walking fatigue; SF LC1 / LC2, required 1.5 / 1.5 for aluminium)
  JX1_AnkleCrank        : 6061-T6  SF 14.44 / 24.70  PASS
  JX1_Thigh_L           : 6061-T6  SF  2.31 /  2.78  PASS
  JX1_HipRollBracket_L  : 6061-T6  SF  2.76 /  3.80  PASS
  JX1_HipYawBracket_L   : 7075-T6  SF  1.77 /  1.58  PASS
  JX1_Shin_L            : 6061-T6  SF  3.37 /  4.17  PASS
  JX1_Foot_L            : 6061-T6  SF  3.50 /  2.03  PASS
  JX1_Pelvis            : 6061-T6  SF  2.90 /  3.44  PASS
  JX1_Torso             : 6061-T6  SF  4.44 /  3.59  PASS
  JX1_ShoulderPitchBracket_L: 6061-T6  SF  2.17 /  1.75  PASS
  JX1_ShoulderRollBracket_L: 6061-T6  SF  2.05 /  1.66  PASS
  JX1_UpperArm_L        : 6061-T6  SF  5.99 /  4.84  PASS
  JX1_Forearm_L         : 6061-T6  SF  3.27 /  2.65  PASS

Compute / electronics : Jetson Nano 4 GB (policy 50 Hz) + 2 x Teensy 4.1 CAN hubs (6 x CAN 1 Mbit/s, 500 Hz), BNO085 IMU,
                        IMX219-83 stereo camera, RobStride on-board FOC drivers
Power                 : 13S2P Samsung 50S (41.6-54.6 V, 468.0 Wh); standing 92.1 W, walking 284.5 W (0.52 m/s), 435.4 W mean / 1681.6 W peak (0.79 m/s); runtime 1.32 h walking, 4.06 h standing  [CALCULATED, lower-body dynamics]
Safety                : dual-path E-stop (motor-bus switch + hub damping), 58 V branch fuses, smart BMS, host/CAN watchdogs
CAD verification      : left leg 25/25 kinematic, 24/25 collision-free (24/24 within the joint/controller limits); right leg 25/25 kinematic, 24/25 collision-free (24/24 within the joint/controller limits); upper body 36/36 kinematic, 36/36 collision-free; whole robot 13/13 kinematic, 11/13 collision-free (11/11 within the joint/controller limits)
Ankle workspace       : 92 % of the pitch x roll box collision-free; coupled limit polygon in joint_map.yaml
MuJoCo                : standing held (max tilt 5.242 deg), squat ok
Walking (MuJoCo, CAD) : slow 0.30 m/s ok, nominal 0.52 m/s ok, fast 0.79 m/s ok, turn 0.18 m/s ok; max tilt 1.2 deg; highest torque left_hip_yaw 100% of peak (fast)  [CALCULATED, MuJoCo]
Push recovery         : walking nominal, 0.1 s torso pushes of 5.3-7.8 N s survived, by direction (fixed footsteps, ankle + hip strategy)  [CALCULATED, MuJoCo]

Learned walking controller (jx1_walk_stand_v7: 47 obs -> 12 leg targets at 50 Hz, PPO in MuJoCo, walk_v7_stand_free iteration 6400)  [CALCULATED, MuJoCo]
  CAD sim-to-sim, flat floor       : 8/8 scenarios upright; 0.8 m/s cmd -> 0.75 m/s, turn 0.5 rad/s -> 0.50 rad/s, peak torque 84% of limit
  CAD sim-to-sim, rough heightfield: 8/8 scenarios upright; 0.8 m/s cmd -> 0.77 m/s, turn 0.5 rad/s -> 0.50 rad/s, peak torque 81% of limit
  command envelope, flat floor  : 118/130 commands tracked, 0 falls; forward +1.09 m/s, backward -0.55, lateral +0.40/-0.38 m/s, yaw +0.87/-0.88 rad/s
  command envelope, rough ground: 119/130 commands tracked, 0 falls; forward +1.10 m/s, backward -0.56, lateral +0.39/-0.38 m/s, yaw +0.87/-0.88 rad/s
  actuator load walking 0.8 m/s (left leg; 1.5 x peak vs actuator peak, RMS vs rated):
    hip_yaw   : peak   8.3 N m x 1.5 =  12.4 <= 36 N m; RMS  2.7 <= 11 N m rated
    hip_roll  : peak  32.2 N m x 1.5 =  48.3 <= 60 N m; RMS 14.6 <= 20 N m rated
    hip_pitch : peak  22.5 N m x 1.5 =  33.8 <= 120 N m; RMS 10.4 <= 40 N m rated
    knee      : peak  59.6 N m x 1.5 =  89.4 <= 120 N m; RMS 23.7 <= 40 N m rated
    ankle_pitch: peak  37.7 N m = 82% of the 46 N m linkage capability; RMS 12.6 N m
    ankle_roll: peak  17.6 N m = 35% of the 51 N m linkage capability; RMS  6.3 N m
  power (run_power_budget model): walking 0.5 m/s 274.1 W, 0.8 m/s 346.6 W mean / 662.9 W peak (15.9 A at 41.6 V vs the 40 A BMS), standing 73.3 W; runtime 1.37 h at 0.5 m/s, 5.11 h standing
  actuator thermal (worst I_rms / rated): hip_yaw 24%, hip_roll 67%, hip_pitch 26%, knee 60%, ankle_motor 84%
  push recovery (0.5 m/s, 0.1 s torso pulse): 29.1-60.0 N s survived (forward 53.4, backward 42.2, left 29.1, right 60.0)
  latency: 0.3 rad/s turn tracked 102% without delay, 82% with 40 ms sensing + 20 ms actuation delay
  ROS 2 jazzy (separate node processes, /cmd_vel -> walk): 3 start paths (python -m, ros2 launch, ros2_control), all upright True; forward 0.31-0.37 m/s at 0.4
  hardware-in-the-loop (hw_node + hub protocol + hub-firmware twin): forward 84% and turn 92% of the 0.3 command, upright True  [CALCULATED, emulated hubs]
  Isaac Lab / Isaac Sim: 89/89 offline checks against the Isaac Lab 2.3.2 / Isaac Sim 5.1 sources; not run in Isaac Sim  [UNVERIFIED runtime]
Robot description     : URDF + xacro (29 links, 23 revolute joints; xacro expansion matches the URDF), MuJoCo MJCF, Isaac Sim import script
Cost (India, landed)  : Rs 712,481 (+15 % contingency = Rs 819,353); actuators 77 %  [ESTIMATED/VERIFIED mix, bom/master_bom.csv]
```

Details: [README](../README.md) · [architecture](architecture.md) · [structural report](../calculations/results/structural/report.md) · [open issues](open_issues.md) · [risk register](risk_register.md) · [BOM](../bom/cost_summary.md)

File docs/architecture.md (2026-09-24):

# JX1 system architecture (v0.5)

JX1 is a 1.23 m, 33.6 kg (CAD), 23-DOF humanoid designed for the lowest practical build cost in India. This document ties together
the mechanical, electrical, computing and software architecture; details live in the linked documents.

## 1. Mechanical architecture

| Area | Decision | Evidence |
|---|---|---|
| Leg kinematics | 6 DOF/leg: hip **yaw → roll → pitch** (axes intersect at the hip centre), knee pitch, **parallel two-motor ankle** (virtual pitch → roll) | `simulation/joint_map.yaml`, `research/reference_robots.md` |
| Dimensions | thigh 0.270 m, shin 0.300 m, ankle→sole 0.050 m, hip spacing 0.200 m, foot 0.210 × 0.095 m | `calculations/design_point.yaml` (v0.3) |
| Actuators | 5 classes, all RobStride 48 V CAN: RS04 (hip pitch, knee), RS03 (hip roll), RS06 (hip yaw, ankle A/B, waist), RS02 (shoulder pitch/roll), RS00 (shoulder yaw, elbow); neck = bus servos | `actuators/actuator_selection.md` |
| Actuator interface | Modular Actuator Interface: stator rear face → parent link, output face + pilot → child link; connector zones face backwards | `actuators/modular_actuator_interface.md` |
| Hip packaging | yaw actuator vertical in the pelvis; roll actuator behind the hip (axis +X, output forward); pitch actuator centred on the hip (output lateral); output faces coplanar with the next mounting face → **the thigh is one 10 mm 6061 plate with run-out flanges** | `CAD/Hip`, `CAD/Thigh` |
| Knee / shin | knee actuator on the thigh plate, output medial; shin = 14 mm medial knee plate + deep joggle block + 10 mm central web carrying ankle motor A (upper, output lateral) and B (lower, output medial) — every bolt stays reachable | `CAD/Shin` |
| Ankle | U-joint cross on HK0810 needle bearings; cranks r = 50 mm; Ø8 steel push rods (M5-tapped ends, POS5 rod ends) to posts 40 mm behind the ankle, ±45 mm lateral; reach −55°…+30° pitch, ±20° roll; collision-free pitch/roll polygon in `joint_map.yaml` | `calculations/jx1calc/ankle.py`, `verification/ankle_workspace_L.json` |
| Materials | **all structure in aluminium** after FEA (every printed PA-CF version failed, SF 0.07–1.23): hip-yaw bracket 7075-T6; hip-roll bracket, thigh, shin, foot, pelvis box, cranks, torso frame, shoulder brackets, upper arms (10/8 mm + gussets), forearms 6061-T6 (laser-cut plates + CNC); ankle cross EN8/EN24; printed PA-CF/PETG-CF only for the neck bracket, head, grippers and covers | `calculations/results/structural/report.md`, [build guide](build_guide.md) |
| Upper body | torso = 6061 plate frame on the waist RS06 + four 2020 posts; battery bay (13S2P) at the bottom, Jetson + hub board + DC-DC above; shoulders RS02 pitch (housing on the torso side plate) → RS02 roll (behind the shoulder, U-bracket) → RS00 yaw → RS00 elbow; ST3215 neck yaw/pitch; head shell with IMX219-83 stereo camera | `tools/cad/build_upper_parts.py`, `CAD/Assemblies/JX1_UpperBody.SLDASM` |

```mermaid
flowchart TB
  P[Pelvis 6061 box<br/>2 x RS06 hip yaw] --> HY[Hip yaw bracket 7075] --> RR[RS03 hip roll] --> HR[Hip roll bracket 6061]
  HR --> PP[RS04 hip pitch] --> TH[Thigh 6061 10 mm + flanges] --> KN[RS04 knee] --> SH[Shin 6061 web + knee plate]
  SH --> AA[RS06 ankle A + crank] --> RA[Rod A]
  SH --> AB[RS06 ankle B + crank] --> RB[Rod B]
  SH --> X[Ankle cross] --> F[Foot]
  RA --> F
  RB --> F
```

## 2. Electrical and computing architecture

```mermaid
flowchart LR
  subgraph HighLevel[High level - Jetson Nano 4 GB]
    POL[RL / ZMP locomotion policy 50 Hz]
    ROS[ROS 2 container: state est., vision, planning, networking]
  end
  subgraph RT[Real-time network - 2 x Teensy 4.1 hubs]
    HA[Hub A: 500 Hz scheduler, watchdogs, E-stop monitor]
    HB[Hub B: 500 Hz scheduler, watchdogs, neck servos UART]
  end
  POL -- USB 480 Mbit/s --> HA
  POL -- USB --> HB
  HA -- CAN1 1 Mbit/s --> LA[L hip yaw / roll / pitch]
  HA -- CAN2 --> LB[L knee / ankle A / ankle B]
  HA -- CAN3 --> AL[L arm x4 + waist]
  HB -- CAN1 --> RA[R hip yaw / roll / pitch]
  HB -- CAN2 --> RB[R knee / ankle A / ankle B]
  HB -- CAN3 --> AR[R arm x4]
  HB -- UART half-duplex --> NK[Neck servos x2]
  IMU[BNO085 IMU] -- SPI --> HA
  CAM[IMX219-83 stereo] -- CSI --> ROS
```

| Layer | Responsibility | Hardware | Rate |
|---|---|---|---|
| Jetson Nano | perception, ROS 2, locomotion policy inference, planning, logging, networking | Jetson Nano 4 GB dev kit (JetPack 4.6.x); ROS 2 Humble in Docker | policy 50 Hz |
| CAN hubs | deterministic bus schedule, command interpolation 50 → 500 Hz, state aggregation, **watchdogs**, soft limits, E-stop monitoring, fault latching | 2 × Teensy 4.1 (3 CAN each) + TJA1462 transceivers on a JX1 carrier PCB | 500 Hz exchange |
| Joint controllers | FOC current loop, MIT-mode PD (position, velocity, torque feed-forward), encoder acquisition, thermal & over-current protection | RobStride on-board drivers (STM32-class, 14-bit abs. encoder) | ≥ 1 kHz internal |
| Sensors | IMU (400 Hz rotation vector) on hub A; foot FSRs (phase 2) on hub ADCs; stereo camera on Jetson CSI | BNO085, FSR406, IMX219-83 | — |

**Why not CAN-FD / why 6 buses:** RobStride speaks classic CAN 1 Mbit/s with 29-bit IDs (≈ 150 bits/frame with stuffing). One
command + one reply per joint every 2 ms = 150 µs per joint → 3 joints per bus = **45 % load at 500 Hz**; 6 joints would be ≈ 90 %
(`research/raw/india_electronics_compute_raw.md` Part C). Teensy 4.1 offers 3 controllers, so two hubs give 6 buses for 21 joints.

**Command interpolation and ankle control (found in the hardware-in-the-loop twin, `ros2_ws/src/jx1_hw`):** the hub ramps
each 50 Hz host target linearly over the next 20 ms (`command_for()` in `firmware/hub/jx1_hub`). This first-order hold
adds ≈ 10 ms of effective lag; it is kept (smooth motor commands) and modelled in RL training, sim-to-sim, `jx1_sim` and
Isaac. The parallel ankle is driven as two independent per-motor MIT loops, so its joint-space pitch/roll stiffness ratio
is fixed by the linkage Jacobian (≈ 1.27); exact joint-space ankle PD would need the hub to add the coupling torques at
500 Hz (optional firmware improvement, OI-20). Hub torque caps are 80 % of the actuator peak (e.g. hip yaw 28.8 of 36 N·m).

**Jetson Nano feasibility:** a 0.1–0.75 MFLOP MLP policy at 50 Hz is < 0.1 % of the Nano's 472 GFLOPS (ESTIMATED). Constraints:
JetPack 4.6.6 is the final release (Ubuntu 18.04, kernel 4.9, CUDA 10.2) and the Nano has **no CAN controller** — hence the
USB-attached hubs, which also make the computer swappable (**Orin Nano**: same 69.6 × 45 mm module, native CAN, supported to 2032).

## 3. Power architecture (48 V)

```mermaid
flowchart LR
  B[13S2P Samsung 50S 468 Wh] --> BMS[JBD 13S 40 A smart BMS] --> XT[XT90-S] --> SW[Flipsky anti-spark 300 A MOSFET switch]
  ES[E-stop XB2BS8442C NC] -. breaks enable .-> SW
  SW --> PDB[JX1 power distribution: 4 x 30 A / 58 V fuses]
  PDB --> F1[Left-leg daisy chain]
  PDB --> F2[Right-leg daisy chain]
  PDB --> F3[Arms + waist]
  PDB --> F4[Aux: DDR-60L-5 5 V Jetson / 12 V buck servos / hubs]
```

| Quantity | Value | Label |
|---|---|---|
| Bus | 13S, 41.6–54.6 V | CALCULATED |
| Average power | 92 W standing, 285 W walking 0.52 m/s, 435 W at 0.79 m/s (CAD masses, iteration 2) | CALCULATED |
| Peak power | 1682 W (40 A at 41.6 V) in the fast gait: pack 50 A cont. (1.24×), but equal to the 40 A BMS rating (OI-26) | CALCULATED |
| Runtime | 1.3 h walking, 4.1 h standing (80 % DoD) | CALCULATED |
| Pack | 26 × Samsung 50S (+2 spare), 1.8 kg cells, ₹20/Wh | VERIFIED prices |

## 4. Software architecture

- `ros2_ws/src/jx1_description` — URDF + xacro generated from the CAD (`tools/sim/build_robot_description.py`, checked by `tools/sim/check_xacro.py`).
- `ros2_ws/src/jx1_hw` — Jetson ↔ CAN-hub bridge speaking the hub USB protocol (50 Hz targets, 500 Hz state) + a firmware digital twin for HIL tests; `jx1_policy` (ONNX policy node), `jx1_sim` (MuJoCo node), `jx1_bringup`; ros2_control xacro.
- Simulation: MuJoCo MJCF (`simulation/mujoco`: validation, ZMP walking, push tests), Isaac Sim import + Isaac Lab task (`simulation/isaac`, UNVERIFIED); RL training and sim-to-sim in `rl/`.
- Firmware: `firmware/hub/` (Teensy): bus scheduler, RobStride MIT-mode driver, watchdogs, limits, E-stop logic.

## 5. Service and repair

- Every actuator is replaceable from its two bolt circles; connectors face backwards with service loops.
- Legs detach from the pelvis at the hip-yaw rear face (6 bolts + 2 connectors per leg).
- Battery slides out of the torso bay through one XT90-S connector.
- Hub PCB is accessible behind the torso back cover; all buses have test points and a spare USB-CAN port.

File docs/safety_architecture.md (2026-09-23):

# JX1 safety architecture (v0.3)

JX1 carries ≈ 468 Wh of Li-ion energy and 21 actuators of up to 120 N·m. Safety is designed in from V1; nothing here is
certified — it is an engineering prototype.

## 1. Stop functions

| Function | Implementation | Category |
|---|---|---|
| Emergency stop | Schneider XB2BS8442C (twist-release, NC). Breaks the enable loop of the motor-bus MOSFET switch **and** signals both hubs (second NC contact to a hub GPIO) | IEC 60204-1 cat. 0 (power removal); robot must be on a gantry/harness during bring-up |
| Software stop | Hub commands MIT-mode zero-velocity damping on every joint, then disables after 2 s | cat. 1-like |
| Communication loss | Hub: no host message for 50 ms → damping; RobStride: CAN timeout (configurable) → stop | — |
| Fault latch | Any actuator fault (over-current, over-temp, encoder) → hub latches → damping on that limb → disable | — |

## 2. Electrical protection

| Hazard | Protection |
|---|---|
| Pack over-/under-voltage, over-current, short, over-temperature | JBD 13S smart BMS (40 A) |
| Branch over-current | 4 × Littelfuse 30 A **58 V** ATO fuses (car fuses rated 32 V are NOT used on the 54.6 V bus) |
| Inrush / arcing on connection | XT90-S anti-spark battery connector + Flipsky anti-spark switch precharge |
| Motor regeneration into a full pack | BMS charge-current limit; hub limits braking torque when bus > 54 V (planned) |
| Charging | dedicated 54.6 V 6 A Li-ion charger; charge outside the robot on a non-flammable surface; LiPo bag |

## 3. Motion limits (firmware)

- **Joint limits:** soft limits = `simulation/joint_map.yaml` limits minus 2°; ankle uses a pitch–roll polygon (open issue OI-3).
- **Current limits:** 80 % of each class's peak phase current; continuous limit from the thermal model.
- **Temperature:** derate from 100 °C winding estimate, stop at 130 °C (RobStride limit 145 °C).
- **Self-collision:** hip-roll adduction > ≈ 8° with the other leg vertical causes leg–leg contact (verified in CAD) → controller
  self-collision check using `simulation/` collision meshes.

## 4. Safe start-up and shutdown

1. Power on with the motor bus switch **open**; Jetson + hubs boot from the aux rail.
2. Hubs enumerate all 21 actuators, read absolute encoders, compare with the stored zero offsets (tolerance 3°).
3. Close the motor-bus switch (precharge), enable joints in **damping mode**, then ramp PD gains over 2 s.
4. Shutdown: crouch-and-sit routine → damping → disable → open the bus switch.

## 5. Pinch and crush zones

| Zone | Risk | Mitigation |
|---|---|---|
| Back of the knee (thigh plate vs shin, RS04 120 N·m) | finger crush up to 120° flexion | knee cover, keep hands clear, reduced gains in teach mode |
| Ankle crank – push rod – foot | pinch between rod and motor housing / foot | printed crank guard (phase 3 covers) |
| Hip yaw bracket under the pelvis | shear between rotating bracket and pelvis bottom plate | 7 mm gap; cover |
| Leg–leg (adduction) | pinch between shins | software self-collision limits |
| Gripper (phase 3) | pinch | force limit |

## 6. Test safety

- All leg bring-up on a lifting gantry (2020/4040 extrusion frame, ₹9–12k ESTIMATED) with a chest harness.
- Single-joint tests with the leg clamped before any closed-loop standing.

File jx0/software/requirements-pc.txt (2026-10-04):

# JX0 on a PC with the simulated body: python -m jx0bot.main --sim --text   (run from jx0/software)
# the simulated body loads jx0/sim/jx0_model.py, which puts the repo's calculations/ (jx1calc) on the path itself
anthropic>=1.0
numpy
pyyaml
mujoco>=3.1
scipy               # jx1calc gait synthesis (imported by the sim model)
pillow
manifold3d          # jx0/cad/preview.py and jx0/verify: the exact CAD solids without SolidWorks
trimesh

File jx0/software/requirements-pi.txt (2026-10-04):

# JX0 on the Raspberry Pi 4 (Raspberry Pi OS 64-bit, Python 3.11): pip install -r requirements-pi.txt
# plus: sudo apt install espeak-ng portaudio19-dev
anthropic>=1.0
numpy
pyyaml
pyserial            # the 17 STS3215 on the serial bus (Waveshare serial bus servo driver)
smbus2              # MPU6050 IMU
gpiozero            # push-to-talk button
vosk                # offline speech recognition
sounddevice         # microphone (INMP441 I2S) and speaker (MAX98357A I2S)
piper-tts           # offline text to speech (falls back to espeak-ng)

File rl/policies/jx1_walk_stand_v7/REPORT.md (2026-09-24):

# JX1 walking policy: `jx1_walk_stand_v7`

| | |
|---|---|
| trainer | rl/train.py (MuJoCo, rsl_rl-style PPO) |
| checkpoint | walk_v7_stand_free/model_latest.pt, iteration 6400 |
| task config | run snapshot (config.yaml next to the checkpoint) |
| robot model | `simulation/mujoco/jx1.xml` (sha256 13e00221a0d0…), 33.61 kg |
| interface | 47 observations → 12 leg joint targets at 50 Hz; 11 joints held at the default pose |
| export check | ONNX max abs diff 2.1e-06 |

## Training

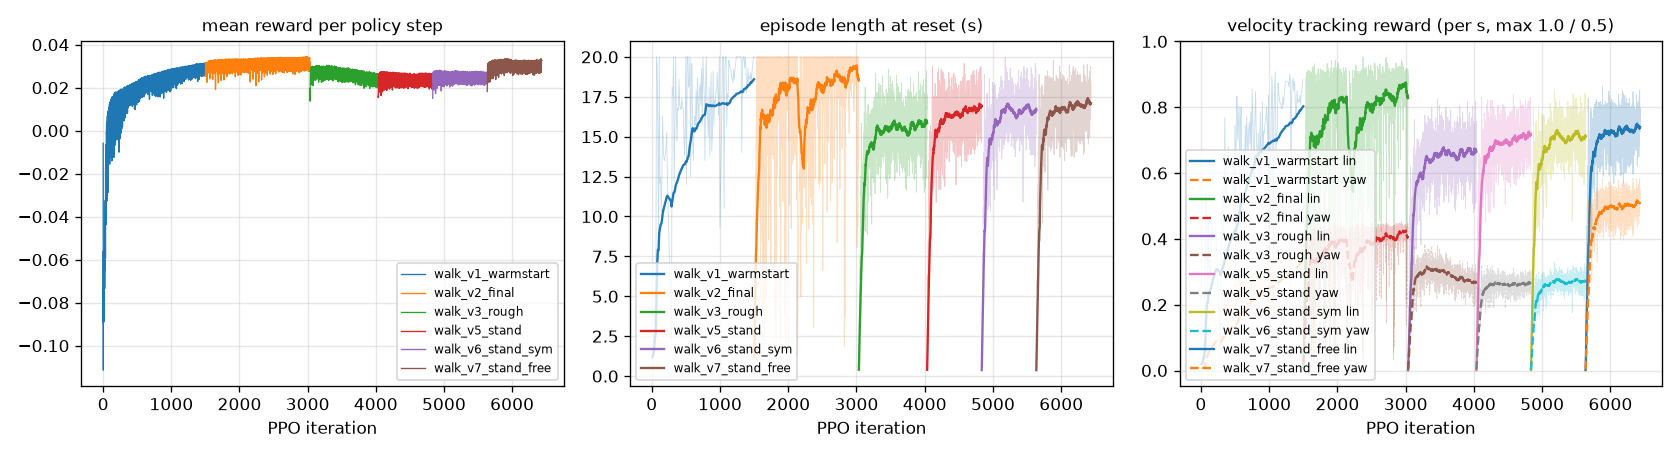
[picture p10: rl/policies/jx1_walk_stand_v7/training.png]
training curves


## Sim-to-sim on the full CAD model, flat floor

`simulation/mujoco/jx1.xml` as generated: CoACD mesh-hull collisions, 2 ms physics, nominal masses, CAN-hub target ramp on. All scenarios upright.

| scenario | command (vx, vy, wz) | result | mean velocity | RMSE | max tilt | peak torque / limit | peak speed / limit | foot lift-offs |
|---|---|---|---|---|---|---|---|---|
| stand | (+0.0, +0.0, +0.0) | upright | (-0.00, -0.00, -0.00) | (+0.00, +0.00, +0.00) | 0.8° | 15% right_knee | 8% right_ankle_pitch_joint | 0.00/s |
| forward_0.5 | (+0.5, +0.0, +0.0) | upright | (+0.48, +0.01, +0.01) | (+0.03, +0.03, +0.06) | 5.8° | 69% left_ankle_pitch | 28% right_ankle_pitch_joint | 2.51/s |
| forward_0.8 | (+0.8, +0.0, +0.0) | upright | (+0.75, +0.02, +0.01) | (+0.05, +0.04, +0.10) | 5.8° | 82% left_ankle_pitch | 27% right_ankle_pitch_joint | 2.51/s |
| backward_0.3 | (-0.3, +0.0, +0.0) | upright | (-0.30, +0.01, +0.02) | (+0.01, +0.02, +0.04) | 5.9° | 46% left_ankle_pitch | 25% left_knee_joint | 2.51/s |
| sidestep_0.2 | (+0.0, +0.2, +0.0) | upright | (-0.03, +0.18, -0.01) | (+0.04, +0.03, +0.02) | 6.4° | 48% left_hip_roll | 26% left_ankle_pitch_joint | 2.34/s |
| turn_0.5 | (+0.0, +0.0, +0.5) | upright | (-0.03, +0.01, +0.50) | (+0.03, +0.03, +0.06) | 4.8° | 45% right_hip_roll | 24% left_knee_joint | 2.34/s |
| walk_turn | (+0.4, +0.0, +0.3) | upright | (+0.38, +0.03, +0.30) | (+0.03, +0.04, +0.06) | 5.6° | 56% right_ankle_pitch | 24% right_ankle_pitch_joint | 2.51/s |
| stand_walk_stand | (+0.0, +0.0, +0.0) at 0 s → (+0.5, +0.0, +0.0) at 3 s → (+0.0, +0.0, +0.0) at 7 s | upright | (+0.21, +0.00, -0.01) | (+0.09, +0.03, +0.06) | 7.1° | 84% left_ankle_pitch | 24% right_knee_joint | 1.22/s (last 2 s: 0.00/s) |

Self-contact between robot bodies (CoACD hulls, whole rollout): none.

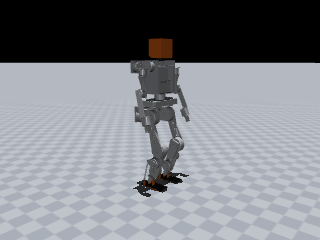
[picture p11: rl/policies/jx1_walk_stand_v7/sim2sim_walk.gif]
walking at 0.5 m/s on the CAD model


## Sim-to-sim on the full CAD model, rough ground (rl/config/jx1_walk_rough.yaml heightfield)

`simulation/mujoco/jx1.xml` as generated: CoACD mesh-hull collisions, 2 ms physics, nominal masses, CAN-hub target ramp on. All scenarios upright.

| scenario | command (vx, vy, wz) | result | mean velocity | RMSE | max tilt | peak torque / limit | peak speed / limit | foot lift-offs |
|---|---|---|---|---|---|---|---|---|
| stand | (+0.0, +0.0, +0.0) | upright | (-0.00, -0.00, -0.00) | (+0.00, +0.00, +0.00) | 0.8° | 16% right_knee | 7% right_ankle_pitch_joint | 0.00/s |
| forward_0.5 | (+0.5, +0.0, +0.0) | upright | (+0.48, +0.00, +0.02) | (+0.03, +0.03, +0.07) | 6.9° | 71% left_ankle_pitch | 26% right_ankle_pitch_joint | 2.51/s |
| forward_0.8 | (+0.8, +0.0, +0.0) | upright | (+0.77, +0.02, +0.01) | (+0.04, +0.04, +0.09) | 5.9° | 81% left_ankle_pitch | 28% right_ankle_pitch_joint | 2.51/s |
| backward_0.3 | (-0.3, +0.0, +0.0) | upright | (-0.30, +0.01, +0.02) | (+0.01, +0.02, +0.04) | 5.9° | 46% left_ankle_pitch | 26% left_ankle_roll_joint | 2.68/s |
| sidestep_0.2 | (+0.0, +0.2, +0.0) | upright | (-0.03, +0.18, -0.01) | (+0.04, +0.03, +0.02) | 6.4° | 49% left_hip_roll | 25% left_ankle_roll_joint | 2.51/s |
| turn_0.5 | (+0.0, +0.0, +0.5) | upright | (-0.03, +0.01, +0.50) | (+0.03, +0.03, +0.05) | 4.8° | 45% right_hip_roll | 24% left_knee_joint | 2.34/s |
| walk_turn | (+0.4, +0.0, +0.3) | upright | (+0.39, +0.02, +0.31) | (+0.02, +0.03, +0.07) | 5.5° | 68% left_ankle_pitch | 24% right_ankle_pitch_joint | 2.51/s |
| stand_walk_stand | (+0.0, +0.0, +0.0) at 0 s → (+0.5, +0.0, +0.0) at 3 s → (+0.0, +0.0, +0.0) at 7 s | upright | (+0.21, +0.00, -0.00) | (+0.09, +0.03, +0.06) | 7.2° | 79% left_ankle_pitch | 24% right_knee_joint | 1.22/s (last 2 s: 0.00/s) |

Self-contact between robot bodies (CoACD hulls, whole rollout): none.

## Command envelope

118/130 commands tracked, 0 falls (upright and |mean v - cmd| <= max(0.1, 20%) per axis (wz: max(0.15, 20%)); 6 s per command). Best tracked pure commands:

- forward +1.09 m/s (command +1.20, peak torque 86%), backward -0.55 m/s (command -0.60, peak torque 73%)
- left +0.40 m/s (command +0.45, peak torque 61%), right -0.38 m/s (command -0.45, peak torque 56%)
- yaw left +0.87 rad/s (command +0.90, peak torque 49%), yaw right -0.88 rad/s (command -0.90, peak torque 46%)

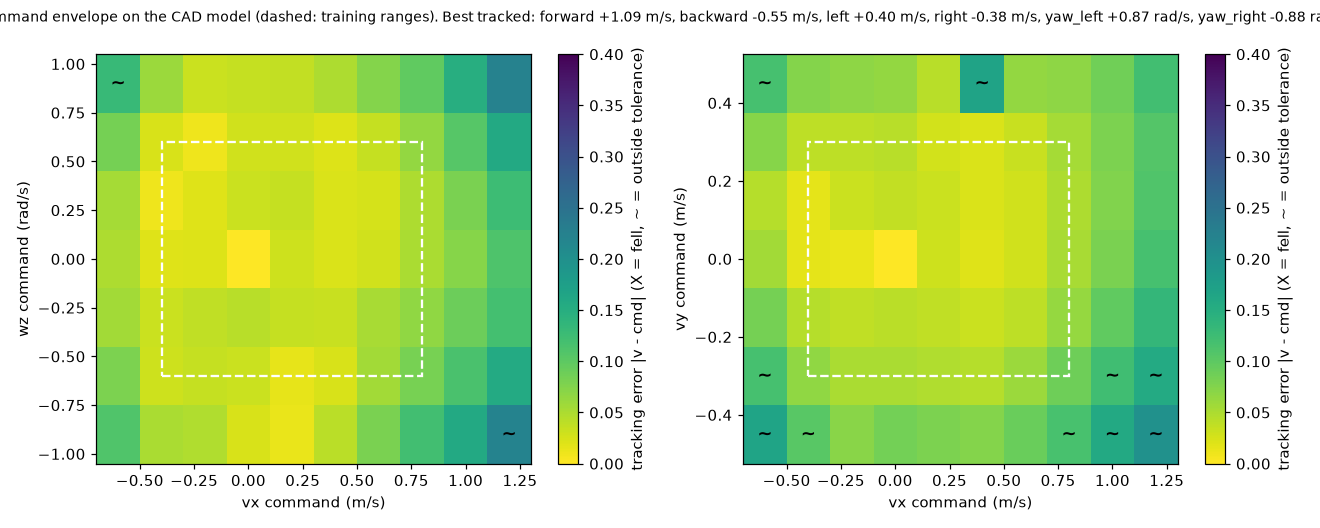
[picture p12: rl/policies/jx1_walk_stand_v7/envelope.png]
command envelope


Self-contact on the CAD hulls: 5/130 commands (0 inside the trained ranges): left_shin_link|right_shin_link in 3 commands (worst +0.00,-0.45,+0.00: 0% of steps); left_shin_link|right_foot_link in 1 commands (worst +0.20,+0.45,+0.00: 1% of steps); left_foot_link|right_foot_link in 2 commands (worst +0.40,+0.45,+0.00: 10% of steps).

## Command envelope (rough ground)

119/130 commands tracked, 0 falls (upright and |mean v - cmd| <= max(0.1, 20%) per axis (wz: max(0.15, 20%)); 6 s per command). Best tracked pure commands:

- forward +1.10 m/s (command +1.20, peak torque 89%), backward -0.56 m/s (command -0.60, peak torque 72%)
- left +0.39 m/s (command +0.45, peak torque 61%), right -0.38 m/s (command -0.45, peak torque 56%)
- yaw left +0.87 rad/s (command +0.90, peak torque 50%), yaw right -0.88 rad/s (command -0.90, peak torque 46%)

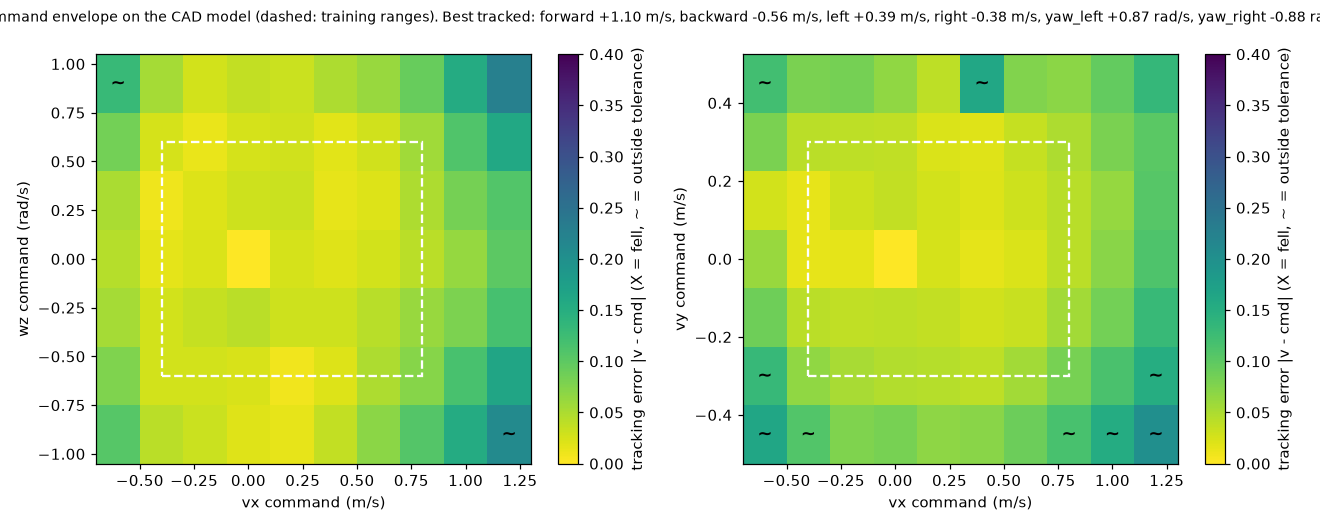
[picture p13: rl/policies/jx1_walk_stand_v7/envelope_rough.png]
command envelope


Self-contact on the CAD hulls: 4/130 commands (1 inside the trained ranges): left_shin_link|right_shin_link in 2 commands (worst +0.00,-0.45,+0.00: 0% of steps); left_foot_link|right_foot_link in 2 commands (worst +0.40,+0.45,+0.00: 14% of steps).

## Latency sensitivity (CAD model, added sensing / actuation delay)

| sensing delay | actuation delay | turn 0.3 rad/s tracked | forward 0.3 m/s tracked |
|---|---|---|---|
| 0 ms | 0 ms | 102% | 92% |
| 10 ms | 0 ms | 97% | 87% |
| 20 ms | 0 ms | 95% | 85% |
| 0 ms | 10 ms | 98% | 87% |
| 10 ms | 10 ms | 95% | 85% |
| 20 ms | 10 ms | 90% | 80% |
| 30 ms | 10 ms | 88% | 77% |
| 40 ms | 20 ms | 82% | 73% |

## Push recovery (0.1 s torso pulse while walking at 0.5 m/s, CAD model)

| direction | largest survived impulse | CoM velocity change |
|---|---|---|
| forward | 53.4 N·s | 1.59 m/s |
| backward | 42.2 N·s | 1.25 m/s |
| left | 29.1 N·s | 0.86 m/s |
| right | 60.0 N·s | 1.78 m/s |

Standing (zero command), largest survived impulse: forward 55.3 N·s, backward 26.2 N·s, left 47.3 N·s, right 53.0 N·s.

## Power (CAD model; electrical model of calculations/run_power_budget.py, no regeneration)

| scenario | command | mean | peak | mean current (nominal V) | runtime, 13S2P 50S (80 %) | foot lift-offs |
|---|---|---|---|---|---|---|
| stand | (+0.0, +0.0, +0.0) | 73 W | 73 W | 1.6 A | 5.11 h | 0.00/s |
| walk_0.3 | (+0.3, +0.0, +0.0) | 234 W | 383 W | 5.0 A | 1.60 h | 2.51/s |
| walk_0.5 | (+0.5, +0.0, +0.0) | 274 W | 571 W | 5.9 A | 1.37 h | 2.51/s |
| walk_0.8 | (+0.8, +0.0, +0.0) | 347 W | 663 W | 7.4 A | 1.08 h | 2.51/s |
| turn_0.5 | (+0.0, +0.0, +0.5) | 225 W | 374 W | 4.8 A | 1.67 h | 2.38/s |

Worst actuator RMS current vs rated: hip_yaw 24% (walk_0.8), hip_roll 67% (walk_0.8), hip_pitch 26% (walk_0.8), knee 60% (walk_0.8), ankle_motor 84% (walk_0.8)

Torque-speed envelope (|tau| / (peak torque * (1 - |omega| / no-load speed at 41.6 V)), linear stall-to-no-load line (conservative: the real curve is flat up to its corner speed); worst point per actuator): hip_yaw 23% (8.4 N·m at 0.1 rad/s, turn_0.5), hip_roll 46% (27.0 N·m at 0.2 rad/s, turn_0.5), hip_pitch 19% (22.0 N·m at 0.5 rad/s, walk_0.8), knee 40% (47.1 N·m at 0.5 rad/s, walk_0.8), ankle_motor 100% (34.2 N·m at 2.0 rad/s, walk_0.8).

## ROS 2 jazzy: separate node processes driven over `/cmd_vel`, measured from `/jx1/odom`

Same script on every path: forward 0.4 m/s for 10 s, turn 0.4 rad/s for 6 s (137.5° commanded), stop.

| started by | forward speed | turn | max tilt | upright |
|---|---|---|---|---|
| python -m (source tree) | 0.37 m/s | 136° | 5.1° | True |
| ros2 launch jx1_bringup mujoco_sim.launch.py (colcon install) | 0.36 m/s | 133° | 5.9° | True |
| ros2 launch jx1_bringup ros2_control.launch.py (colcon install) | 0.31 m/s | 121° | 6.4° | True |

| phase | command | distance | mean speed | yaw change | min pelvis z | max tilt |
|---|---|---|---|---|---|---|
| forward | (+0.4, +0.0, +0.0) | 2.69 m | 0.37 m/s | +4.7° | 0.565 m | 4.4° |
| turn | (+0.0, +0.0, +0.4) | 0.10 m | 0.02 m/s | +136.5° | 0.561 m | 5.1° |
| stop | (+0.0, +0.0, +0.0) | 0.03 m | 0.01 m/s | -2.0° | 0.561 m | 3.0° |

## Hardware-in-the-loop: policy → `hw_node` → hub protocol → hub-firmware twin → physics

`jx1_policy -> jx1_hw hw_node -> hub protocol over TCP -> fake_hub (firmware law) -> MuJoCo`. RUN accepted: True, upright: True, hub faults at the end: none.

| phase | command | distance | mean speed | yaw change | min pelvis z | max tilt |
|---|---|---|---|---|---|---|
| stand | (+0.0, +0.0, +0.0) | 0.00 m | 0.00 m/s | -0.3° | 0.585 m | 0.8° |
| forward | (+0.3, +0.0, +0.0) | 2.53 m | 0.25 m/s | +6.6° | 0.564 m | 6.0° |
| turn | (+0.0, +0.0, +0.3) | 0.13 m | 0.02 m/s | +95.2° | 0.559 m | 4.9° |
| stop | (+0.0, +0.0, +0.0) | 0.01 m | 0.00 m/s | -0.2° | 0.564 m | 2.8° |

At the top trained speed through the same chain (`hw_loop_check.py --fast`, hub torque caps 80 % of peak): 0.8 m/s commanded -> 0.68 m/s, max tilt 6.0°, upright True.

Started as on the robot, `ros2 launch jx1_hw hardware.launch.py hil:=true (colcon install)`: forward 0.25 m/s at 0.3, turn 96° of 103° commanded, upright True, RUN accepted True.

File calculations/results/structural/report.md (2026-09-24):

# JX1 structural analysis (OI-4) — voxel FEA + hand calculations

Body weight 269 N (mass 27.47 kg). Actuator peaks: hip yaw 36, hip roll 60, hip pitch 120, knee 120, ankle motor 36 N·m.

**Load model (leg chain: hip brackets, pelvis, thigh, shin)** — `calculations/structural/leg_loads.py`:
* **LC1 strength**: 2160 ground-reaction samples (8 poses × CoP grid over the sole × 5 GRF directions × 3 free yaw moments) at 3 BW, propagated through the leg kinematics; whenever a joint (or an ankle motor through the parallel linkage) would exceed its actuator peak the GRF is scaled to the saturation point (2034 samples scaled, min scale 0.23). Required SF 1.5 on minimum yield (6061-T6) / 2.0 on conditioned strength (PA-CF).
* **LC2 fatigue**: fast walk 0.79 m/s, nominal walk 0.52 m/s and 15°/step turning time series (inverse-dynamics joint torques → equivalent foot wrench), Goodman mean/amplitude per element, required SF 1.5.
* Foot and ankle crank: capped envelope cases (foot patch loads limited by the ankle's torque capability; crank rod force from the RS06 peak).
* SF = 1 / (99.9th-percentile failure index away from load/support introduction). Method validated against closed-form solutions (`test_voxel_fea.py`). Label: CALCULATED (linear, bonded interfaces, ASSUMED printed-material knockdowns).

| Part | Material / print build axis | Elements | SF LC1 (req) | SF LC2 fatigue (req) | Result | Worst location [mm] |
|---|---|---|---|---|---|---|
| JX1_Thigh_L | 6061-T6 | 40278 | 2.31 (1.5) | 2.78 (1.5) | PASS | [23.0, 35.0, -205.0] |
| JX1_HipRollBracket_L | 6061-T6 | 20997 | 2.76 (1.5) | 3.8 (1.5) | PASS | [-69.0, -19.0, -39.0] |
| JX1_HipYawBracket_L | 7075-T6 | 38205 | 1.77 (1.5) | 1.58 (1.5) | PASS | [-131.0, 3.0, 55.0] |
| JX1_Shin_L | 6061-T6 | 54333 | 3.37 (1.5) | 4.17 (1.5) | PASS | [-15.0, -20.0, -271.0] |
| JX1_Foot_L | 6061-T6 | 23194 | 3.5 (1.5) | 2.03 (1.5) | PASS | [25.0, 11.0, -41.0] |
| JX1_Pelvis | 6061-T6 | 61436 | 2.9 (1.5) | 3.44 (1.5) | PASS | [71.0, 133.0, 131.0] |
| JX1_AnkleCrank | 6061-T6 | 21080 | 14.44 (1.5) | 24.7 (1.5) | PASS | [-37.5, -18.5, 5.5] |
| JX1_Torso | 6061-T6 **(recommended)** | 136604 | 4.44 (1.5) | 3.59 (1.5) | PASS | [51.0, 79.0, 5.0] |
| JX1_Torso | PA-CF build z | 136604 | 0.7 (2.0) | 0.42 (1.5) | **FAIL** | [-11.0, 25.0, 5.0] |
| JX1_ShoulderPitchBracket_L | 6061-T6 **(recommended)** | 125734 | 2.17 (1.5) | 1.75 (1.5) | PASS | [-45.5, 5.5, 42.5] |
| JX1_ShoulderPitchBracket_L | PA-CF build x | 125734 | 0.24 (2.0) | 0.15 (1.5) | **FAIL** | [-45.5, 5.5, -42.5] |
| JX1_ShoulderPitchBracket_L | PA-CF build y | 125734 | 0.41 (2.0) | 0.25 (1.5) | **FAIL** | [-45.5, 5.5, -42.5] |
| JX1_ShoulderPitchBracket_L | PA-CF build z | 125734 | 0.32 (2.0) | 0.19 (1.5) | **FAIL** | [-45.5, 5.5, 42.5] |
| JX1_ShoulderRollBracket_L | 6061-T6 **(recommended)** | 44276 | 2.05 (1.5) | 1.66 (1.5) | PASS | [-33.5, 22.5, -13.5] |
| JX1_ShoulderRollBracket_L | PA-CF build x | 44276 | 0.23 (2.0) | 0.14 (1.5) | **FAIL** | [-33.5, 31.5, -13.5] |
| JX1_ShoulderRollBracket_L | PA-CF build y | 44276 | 0.28 (2.0) | 0.17 (1.5) | **FAIL** | [-33.5, 22.5, -13.5] |
| JX1_ShoulderRollBracket_L | PA-CF build z | 44276 | 0.36 (2.0) | 0.21 (1.5) | **FAIL** | [-33.5, 15.5, -18.5] |
| JX1_UpperArm_L | 6061-T6 **(recommended)** | 133148 | 5.99 (1.5) | 4.84 (1.5) | PASS | [23.5, -25.5, -82.5] |
| JX1_UpperArm_L | PA-CF build x | 133148 | 0.84 (2.0) | 0.5 (1.5) | **FAIL** | [23.5, -25.5, -82.5] |
| JX1_UpperArm_L | PA-CF build y | 133148 | 1.23 (2.0) | 0.74 (1.5) | **FAIL** | [-24.5, -26.5, -84.5] |
| JX1_UpperArm_L | PA-CF build z | 133148 | 0.73 (2.0) | 0.44 (1.5) | **FAIL** | [23.5, -25.5, -82.5] |
| JX1_Forearm_L | 6061-T6 **(recommended)** | 73032 | 3.27 (1.5) | 2.65 (1.5) | PASS | [-10.5, 30.5, -14.5] |
| JX1_Forearm_L | PA-CF build x | 73032 | 0.45 (2.0) | 0.27 (1.5) | **FAIL** | [10.5, 30.5, -14.5] |
| JX1_Forearm_L | PA-CF build y | 73032 | 0.56 (2.0) | 0.34 (1.5) | **FAIL** | [-10.5, 30.5, -14.5] |
| JX1_Forearm_L | PA-CF build z | 73032 | 0.36 (2.0) | 0.21 (1.5) | **FAIL** | [5.5, 25.5, -21.5] |

## Interface compliance (unit loads)

| Part | Interface | translation [mm/kN] | rotation [deg per 100 N·m] |
|---|---|---|---|
| JX1_Thigh_L | knee | [0.7458, 3.7481, 0.3328] | [1.1871, 0.0471, 1.7081] |
| JX1_HipRollBracket_L | leg | [0.0646, 0.2491, 0.052] | [0.2806, 0.0156, 0.5987] |
| JX1_HipYawBracket_L | leg | [0.8448, 1.519, 1.6288] | [0.6211, 1.0395, 0.2367] |
| JX1_Shin_L | fork | [0.2488, 7.4568, 0.0352] | [2.1782, 0.1824, 1.3216] |
| JX1_Foot_L | toe patch GRF (ankle-torque capped) | [0.0567, 0.4649, 1.4021] | [1.5337, 2.2517, 0.1846] |
| JX1_Pelvis | leg | [0.5581, 1.3261, 0.176] | [0.4197, 0.175, 0.0059] |
| JX1_AnkleCrank | rod-end stud (rod force; radial component up to 0.7 F at +-45 deg crank) | [0.0028, 0.0081, 0.1251] | [2.2353, 3.7026, 0.3691] |
| JX1_Torso | left shoulder-pitch housing (arm wrench @ shoulder centre) | [3.8377, 3.3647, 1.6193] | [1.0509, 0.4469, 0.2176] |
| JX1_ShoulderPitchBracket_L | shoulder-roll housing (arm wrench @ roll centre) | [1.0128, 1.382, 2.1076] | [1.5022, 0.622, 3.3117] |
| JX1_ShoulderRollBracket_L | shoulder-yaw housing (arm wrench @ roll centre) | [0.1025, 0.0541, 0.2198] | [0.8622, 2.2299, 0.0396] |
| JX1_UpperArm_L | elbow housing (forearm wrench @ elbow) | [0.5382, 0.426, 0.1656] | [1.0374, 0.1109, 0.8965] |
| JX1_Forearm_L | gripper mount (hand wrench @ hand frame) | [1.9761, 24.4128, 2.2831] | [17.1862, 0.9722, 10.6951] |

## Design history (voxel variant studies, same consistent loads)

Variants start from the voxelised first-iteration CAD (printed PA-CF brackets) and add material or change the alloy (`part_variants.py`, `thigh_variants.py`); they drove the redesign now in the CAD.

| Part | Variant | Material | Mass (solid) kg | SF LC1 | SF LC2 |
|---|---|---|---|---|---|
| foot | F0_pacf | PA-CF build z | 0.274 | 0.74 | 0.33 |
| foot | F1_al | 6061-T6 | 0.597 | 4.29 | 2.5 |
| hip_roll | R0_pacf | PA-CF build y | 0.18 | 0.35 | 0.37 |
| hip_roll | R1_al | 6061-T6 | 0.392 | 1.96 | 2.64 |
| hip_roll | R2_al_12mm | 6061-T6 | 0.611 | 4.42 | 6.68 |
| hip_roll | R3_al_ribs | 6061-T6 | 0.78 | 4.25 | 6.19 |
| hip_roll | R4_al_ribs_gussets | 6061-T6 | 0.846 | 6.45 | 9.35 |
| hip_yaw | Y0_pacf | PA-CF build z | 0.312 | 0.08 | 0.07 |
| hip_yaw | Y1_al | 6061-T6 | 0.68 | 0.7 | 0.79 |
| hip_yaw | Y1_7075 | 7075-T6 | 0.708 | 1.25 | 1.14 |
| hip_yaw | Y12_7075_back12 | 7075-T6 | 0.856 | 1.65 | 1.42 |
| hip_yaw | Y13_7075_back12_keel | 7075-T6 | 0.864 | 1.87 | 1.6 |
| hip_yaw | Y2_al_back16 | 6061-T6 | 0.965 | 1.06 | 1.09 |
| hip_yaw | Y3_al_box | 6061-T6 | 1.36 | 1.25 | 1.33 |
| hip_yaw | Y6_al_raised_box | 6061-T6 | 2.207 | 4.03 | 4.43 |
| hip_yaw | Y7_al_raised_light | 6061-T6 | 1.254 | 2.12 | 2.32 |
| hip_yaw | Y8_al_raised_walls | 6061-T6 | 1.596 | 2.18 | 2.39 |
| hip_yaw | Y4_al_box_keel | 6061-T6 | 1.45 | 1.36 | 1.52 |
| pelvis | P0_pacf | PA-CF build z | 0.858 | 0.9 | 0.73 |
| pelvis | P1_al | 6061-T6 | 1.867 | 5.82 | 6.72 |
| shin | S0_pacf | PA-CF build y | 0.396 | 0.35 | 0.43 |
| shin | S1_al | 6061-T6 | 0.863 | 2.06 | 3.46 |
| shin | S2_al_deep_joggle | 6061-T6 | 0.978 | 2.16 | 3.7 |
| shin | S3_al_knee14 | 6061-T6 | 1.073 | 3.12 | 4.04 |
| shin | S4_al_knee14_flanges | 6061-T6 | 1.096 | 3.23 | 4.04 |
| upper_arm | U0_al | 6061-T6 | 0.189 | 1.34 | 1.08 |
| upper_arm | U1_al_elbow10 | 6061-T6 | 0.266 | 1.95 | 1.57 |
| upper_arm | U2_al_elbow10_gussets | 6061-T6 | 0.323 | 2.34 | 1.89 |
| upper_arm | U3_al_elbow10_gussets_yaw8 | 6061-T6 | 0.334 | 3.12 | 2.52 |
| thigh | V0 | 6061-T6 | 0.68 | 1.01 | 1.19 |
| thigh | V1 | 6061-T6 | 0.712 | 1.35 | 1.6 |
| thigh | V2 | 6061-T6 | 0.804 | 1.34 | 1.7 |
| thigh | V3 | 6061-T6 | 1.103 | 2.91 | 3.35 |
| thigh | V4 | 6061-T6 | 1.195 | 2.98 | 3.73 |
| thigh | V5 | 6061-T6 | 1.023 | 3.27 | 3.65 |
| thigh | V6 | 6061-T6 | 1.115 | 3.14 | 3.65 |
| thigh | V7 | 6061-T6 | 0.723 | 1.64 | 1.94 |
| thigh | V9 | 6061-T6 | 0.873 | 2.35 | 2.81 |

## Hand calculations

```json
{
 "ankle_rod_buckling": {
  "rod_force_LC1_N": 720.0,
  "rod_force_LC2_N": 170.0,
  "pinned_pinned_K": 1.0,
  "options": {
   "M5 threaded rod (d3 = 4.019 mm)": {
    "A": {
     "length_mm": 182.7,
     "P_cr_N": 731.0,
     "SF_LC1": 1.02
    },
    "B": {
     "length_mm": 95.3,
     "P_cr_N": 2687.0,
     "SF_LC1": 3.73
    }
   },
   "M6 threaded rod (d3 = 4.773 mm)": {
    "A": {
     "length_mm": 182.7,
     "P_cr_N": 1454.0,
     "SF_LC1": 2.02
    },
    "B": {
     "length_mm": 95.3,
     "P_cr_N": 5344.0,
     "SF_LC1": 7.42
    }
   },
   "Ø8 solid 304 rod, M5 tapped ends": {
    "A": {
     "length_mm": 182.7,
     "P_cr_N": 11478.0,
     "SF_LC1": 15.94
    },
    "B": {
     "length_mm": 95.3,
     "P_cr_N": 42179.0,
     "SF_LC1": 58.58
    }
   }
  },
  "required_SF": 3.0,
  "decision": "Ø8 solid 304 rod with M5 tapped ends (M5 threaded rod buckles below the RS06 peak rod force)"
 },
 "rod_end_PHS5": {
  "static_SF_LC1": 7.96,
  "dynamic_rating_over_LC2": 19.2
 },
 "ankle_pins": {
  "pin_force_LC1_N": 2260.0,
  "double_shear_MPa": 22.5,
  "SF_shear_on_0.577Y": 9.1,
  "tine_bearing_SF_on_conditioned_xy": 4.44,
  "pin_bearing": "HK0810 drawn-cup needle bearings (8x12x10, BOM) pressed into the printed tines: bore pressure on the 12 mm OD",
  "tine_bore_pressure_MPa": 10.5,
  "decision": "keep HK0810 needle bearings (static rating >> 1.1 kN per bearing); ream printed bores for a 0.02-0.04 mm press fit"
 },
 "bolted_joints_LC1": {
  "hip_yaw_RS06_output_M3_12.9": {
   "bolts": "6 x M3 12.9 on PCD 46 mm",
   "max_bolt_tension_N": 2079.0,
   "preload_70pct_proof_N": 3415.0,
   "separation_SF": 1.64,
   "slip_torque_SF": 1.96
  },
  "hip_yaw_RS06_output_M3_8.8": {
   "bolts": "6 x M3 8.8 on PCD 46 mm",
   "max_bolt_tension_N": 2079.0,
   "preload_70pct_proof_N": 2042.0,
   "separation_SF": 0.98,
   "slip_torque_SF": 1.17
  },
  "hip_pitch_RS04_output_M5_12.9": {
   "bolts": "8 x M5 12.9 on PCD 64 mm",
   "max_bolt_tension_N": 567.0,
   "preload_70pct_proof_N": 9642.0,
   "separation_SF": 17.01,
   "slip_torque_SF": 3.09
  },
  "knee_RS04_output_M5_12.9": {
   "bolts": "8 x M5 12.9 on PCD 64 mm",
   "max_bolt_tension_N": 567.0,
   "preload_70pct_proof_N": 9642.0,
   "separation_SF": 17.01,
   "slip_torque_SF": 3.09
  },
  "ankle_RS06_output_M3_12.9": {
   "bolts": "6 x M3 12.9 on PCD 46 mm",
   "max_bolt_tension_N": 609.0,
   "preload_70pct_proof_N": 3415.0,
   "separation_SF": 5.61,
   "slip_torque_SF": 1.96
  },
  "note": "bolt patterns are ASSUMED until RobStride drawings are dimensioned (OI-1); proof strengths ISO 898-1 (8.8: 580 MPa for M3-M5 is conservative vs 600-640; 12.9: 970 MPa)"
 },
 "actuator_output_bearing_moments": {
  "hip_yaw_RS06_tilting_moment_Nm": {
   "LC1": 134.2,
   "LC2_walk": 66.0
  },
  "hip_roll_RS03_tilting_moment_Nm": {
   "LC1": 125.3,
   "LC2_walk": 62.1
  },
  "status": "UNVERIFIED — RobStride manuals (rev. 260713) publish no output-bearing axial/radial/moment ratings; request from RobStride or add an external yaw support bearing (risk R17)"
 }
}
```

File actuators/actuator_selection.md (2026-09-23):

# JX1 actuator selection (V1 baseline) and trade study

**Status:** SELECTED for V1 prototype, 2026-09-24. Datasheet values: [`actuator_catalog.yaml`](actuator_catalog.yaml) (VERIFIED, official
RobStride manuals). Requirements: [`../requirements/robot_requirements.yaml`](../requirements/robot_requirements.yaml) (CALCULATED).

## 1. Decision

| Class | Product | Peak / rated | Mass | Joints | Qty | Landed ₹ each (ESTIMATED) |
|---|---|---|---|---|---:|---:|
| **XL** | RobStride RS04 | 120 / 40 N·m, 20.9 rad/s | 1.42 kg | hip pitch, knee | 4 | 34,634 |
| **L** | RobStride RS03 | 60 / 20 N·m, 20.9 rad/s | 0.88 kg | hip roll | 2 | 30,560 |
| **M** | RobStride RS06 | 36 / 11 N·m, 50.3 rad/s | 0.62 kg | hip yaw, ankle A/B, waist yaw | 7 | 28,522 |
| **S** | RobStride RS02 | 17 / 6 N·m, 42.9 rad/s | 0.38 kg | shoulder pitch/roll | 4 | 19,694 |
| **XS** | RobStride RS00 | 14 / 5 N·m, 33.0 rad/s | 0.31 kg | shoulder yaw, elbow | 4 | 16,978 |
| servo | Waveshare ST3215 | 1.9 N·m stall | 0.055 kg | neck yaw/pitch | 2 | 2,159 (Robu, in stock) |

All RobStride classes share one electrical/software interface: **48 V, classic CAN 2.0B 1 Mbit/s, 14-bit absolute encoder,
XT30 power + GH1.25 CAN connectors, private/CANopen/MIT protocols** — one driver stack for 21 joints.

## 2. Why these (requirement check, iteration 1-B, 27.5 kg robot)

| Joint | Required peak / cont. / speed | Selected capability | Margin |
|---|---|---|---|
| hip pitch | 85.4 N·m / 25.9 N·m / 12.1 rad/s | RS04 120 / 40 / 20.9 | 1.41 / 1.54 / 1.73 |
| knee | 71.0 / 29.5 / 12.2 | RS04 120 / 40 / 20.9 | 1.69 / 1.36 / 1.71 |
| hip roll | 50.0 / 17.3 / 6.0 | RS03 60 / 20 / 20.9 | 1.20 / 1.16 / 3.5 |
| hip yaw | 37.3 / 8.0 / 6.0 | RS06 36 / 11 / 50.3 | **0.97** / 1.38 / 8.4 |
| ankle motor | 32.0 / 3.4 / 8.8 | RS06 36 / 11 / 50.3 | 1.13 / 3.2 / 5.7 |
| ankle pitch (joint, via linkage) | 40.5 N·m | 46–58 N·m over −55…+30° | ≥ 1.13 |
| ankle roll (joint, via linkage) | 12.6 N·m | 51–65 N·m | ≥ 4 |

Requirement policy: peak = max(1.5 × dynamic peak over walking 0.30/0.52/0.79 m/s, turning and squat; 1.25 × static worst case incl.
single-leg toe/heel/edge stands); continuous = 1.3 × max(walking RMS, standing); speed = max(1.3 × peak, floor).
Thermal: worst RMS phase current ≤ 61 % of rated for every leg actuator (`calculations/run_power_budget.py`).

**Hip yaw is 3 % under the policy peak.** The dynamic peak (24.9 N·m) occurs only in the 0.79 m/s gait; options are (a) accept and cap
yaw torque use in the controller, (b) RS03 on hip yaw (+0.26 kg per leg, +₹2,040 each) — recorded as open issue OI-2.

## 3. Trade study (what was rejected and why)

Evidence: [`../research/raw/actuator_technology_raw.md`](../research/raw/actuator_technology_raw.md) (≈110 actuators),
[`../research/raw/india_robu_browser_sourcing_raw.md`](../research/raw/india_robu_browser_sourcing_raw.md).

| Option | Cost per peak N·m | Result |
|---|---|---|
| **Indian-stocked integrated actuators** — CubeMars AK10-9 ₹1,04,809, AK80-9 ₹79,739, AK60-6 ₹33,919 (Robu); xTerra QDD A2 ₹94,400; MyActuator X8 ₹85,475 (Amazon.in) | ₹2,200–7,900 / N·m | **Rejected**: 3–8× the import route; most out of stock |
| **RobStride (selected)** — official store, import | ₹290 (RS04) – ₹1,210 (RS00) / N·m landed | Best cost per N·m with ≥ 20 rad/s; single protocol family; K-Scale K-Bot precedent |
| Damiao DM-J10010L / DM-J4340P / DM-J8009P | similar to RobStride (reseller prices) | Kept as **alternative** (DM-J4340P: 40 N·m at 381 g, but 11.7 rad/s); mixing vendors doubles firmware work |
| SteadyWin GIM8108-8 / GIM8115-9 (ships to India) | ~$5–6 / N·m | Alternative for M class; 22 N·m too low for ankle pairs |
| **DIY** (drone BLDC from Robu + printed/laser-cut cycloid + FOC driver) — MAD 8318 ₹14,479, Eaglepower 8308 ₹11,579, Tarot 6012 ₹7,249; drivers: NDrive Z1 ₹13,999, ODESC ₹7,350; B-G431B-ESC1 sold out in India | ≥ ₹22,000 per 50–60 N·m joint before development/testing | **Deferred to V2 localisation**: not cheaper than import at JX1 scale (Berkeley Humanoid Lite DIY units cost US$94–188 and walk at 6 N·m caps); no published printed-reducer life data above ~60 h |
| Hobby/bus servos (Feetech STS3215, Waveshare ST3215 ₹2,159, Hiwonder) | cheap | Only for the **neck** (position-controlled, low torque) |

## 4. Procurement notes

- Landed cost = USD list × ₹95.96 × 1.3228 (HS 8501 effective duty) × 1.07 shipping (ESTIMATED). China-distributor route
  (CNY list, e.g. RS04 ¥1,199) is ≈ 34 % cheaper: ₹3.59 lakh vs ₹5.46 lakh for all 21 actuators.
- Buy **2 spares** of RS04 and RS06 for the leg bring-up (not in BOM total; see open issues).
- Bench-test one of each class before the full order: torque–speed at 48 V, thermal soak at 30–50 % peak, backlash, CAN timing.

## 5. V2 localisation path (DIY joint module)

The [Modular Actuator Interface](modular_actuator_interface.md) keeps the leg structure independent of the actuator make. A
locally built module (Indian BLDC + laser-cut steel cycloid + STM32G431 FOC board, ₹572 MCU at Evelta) must match the MAI
envelope, bolt patterns, 48 V / CAN protocol and the torque–speed table above to be a drop-in replacement.

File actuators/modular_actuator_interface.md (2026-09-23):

# JX1 Modular Actuator Interface (MAI) — v0.3

The MAI lets any actuator that fits a class envelope drop into the JX1 structure without redesigning links. CAD: every
class exists as a native parametric stator/rotor pair in `CAD/Actuators/` (`JX1_ACT_<class>_Housing` / `_Output`),
generated by `tools/cad/build_actuators.py` from `tools/cad/params.py`. Brackets reference only MAI features.

## 1. Frame and datums (all classes)

| Datum | Definition | CAD feature |
|---|---|---|
| Joint axis | +Z of the actuator frame, pointing out of the output face | `AX_Joint` (both parts) |
| Interface plane | housing/output split plane, z = 0 | `Front Plane` (both parts) |
| Output mounting face | z = +T_OUT (child link bolts here) | `PL_Mount` (output) |
| Rear mounting face | z = −L_HOUSING (parent link bolts here) | `PL_Rear` (housing) |
| Clocking reference | +X of the actuator frame; connector zone on +Y | `Top Plane` / `Right Plane` |
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

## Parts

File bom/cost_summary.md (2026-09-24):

# JX1 cost summary (INR) — generated 2026-09-24

Generated by `bom/build_bom.py` from `bom/master_bom.csv`. Imports use USD list × ₹95.96 × 1.323 duty × 1.07 shipping (ESTIMATED landed cost). Printed/machined parts are ESTIMATED until quotes are received.

## Totals

| Item | INR |
|---|---:|
| Legs | 418,394 |
| Pelvis | 5,094 |
| Electronics | 49,048 |
| Power | 31,606 |
| Torso | 31,522 |
| Arms | 152,688 |
| Head | 11,406 |
| Manufacturing | 12,723 |
| **Robot total (excl. deferred grippers)** | **712,481** |
| Prototype contingency 15 % | 106,872 |
| **Total with contingency** | **819,353** |

- **Lower body (legs + pelvis) = ₹423,488**; Phase 1 (lower body + compute + power + consumables) = ₹513,833.
- Actuators = ₹545,998 (**77 %** of the robot).
- Buying the same RobStride units through a China distributor (CNY list, ₹13.52/CNY, +5 % agent) = ₹358,924 (saves ₹187,074).
- USD/INR 95.96, duty 32.28 %, shipping 7 % (see script header for labels).

## Top 10 cost lines (cost-reduction loop input)

| # | ID | Part | Model | Qty | Total INR | Alternative | Alt. unit INR |
|---|---|---|---|---:|---:|---|---:|
| 1 | JX1-003 | Joint actuator | RobStride RS06 | 6 | 171,132 | Same unit via China distributor (CNY 849) | 17000 |
| 2 | JX1-001 | Joint actuator | RobStride RS04 | 4 | 138,536 | Same unit via China distributor (CNY 1199) | 24008 |
| 3 | JX1-005 | Joint actuator | RobStride RS02 | 4 | 78,776 | Same unit via China distributor (CNY 699) | 13997 |
| 4 | JX1-006 | Joint actuator | RobStride RS00 | 4 | 67,912 | Same unit via China distributor (CNY 598) | 11974 |
| 5 | JX1-002 | Joint actuator | RobStride RS03 | 2 | 61,120 | Same unit via China distributor (CNY 999) | 20004 |
| 6 | JX1-023 | High-level computer | Waveshare JETSON-NANO-DEV-KIT (Nano 4 GB module, 16 GB eMMC, 64 GB card) | 1 | 30,900 | Jetson Orin Nano Super dev kit (upgrade path, native CAN) | 49999.99 |
| 7 | JX1-004 | Joint actuator | RobStride RS06 | 1 | 28,522 | Same unit via China distributor (CNY 849) | 17000 |
| 8 | JX1-007 | Hip yaw bracket (L/R) | JX1_HipYawBracket | 2 | 13,000 | 6061-T6 raised box-beam variant (Y7, +18 mm hip stack) | 5500 |
| 9 | JX1-030 | Li-ion cells | Samsung INR21700-50S | 28 | 10,176 | Molicel P45B (Robokits ₹481) | 481 |
| 10 | JX1-009 | Thigh (L/R) | JX1_Thigh | 2 | 9,000 | 8 mm plate + run-out flanges (V7, SF 1.64/1.94, 0.72 kg) | 4000 |

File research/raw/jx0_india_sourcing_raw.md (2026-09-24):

# JX0 India sourcing (RAW)

**Date: 2026-09-24.** **Method:** live store checks on 2026-09-24.
- **Robu.in:** in-app browser, using the site's own search API (`POST /api/search/`, the same call the search page makes) plus product pages.
- **Shopify stores (Robocraze, ThinkRobotics, Quartz Components, Indian Hobby Center):** curl of `search/suggest.json` and `products/<handle>.js`, which give variant-level price and availability.
- **Evelta, ElectronicsComp, Probots, Hubtronics, Zbotic, IndustryBuying:** curl of search and product pages.
- **Waveshare specs:** waveshare.com wiki, product pages, 2D drawing zip and memory-table spreadsheets.

Nothing was bought. No accounts were created and no forms were filled.

Project: JX0, a ~45 cm, ~2 kg 3D-printed hobby humanoid; total budget under ₹50,000; student build in India.

**Legend**
- **GST incl.?**
  - **Yes:** the page states the price includes GST. Robu shows "(Incl. GST)". Robocraze shows "Incl. GST (No Hidden Charges)". Evelta shows "inc. GST" and "ex. GST" side by side. IndustryBuying shows "(Incl. of all taxes)". Probots and Zbotic show the GST split. Hubtronics shows "Ex Tax" under the incl. price.
  - **Ex:** the page gives the price without GST. ElectronicsComp shows "(Excluding 18% GST)". For those rows I add the incl. figure as ×1.18, marked "calc".
  - **Not stated:** no GST wording found on the product page or the policy pages checked (ThinkRobotics, Quartz Components, Indian Hobby Center).
- **Stock**
  - **IN:** Robu API `in_stock=true` or "Add to Cart"; Shopify variant `available=true`; or a stock count on the page.
  - **OOS:** out of stock or sold out.
  - **BO:** backorder.
- Prices are ₹ as displayed on 2026-09-24. They are not landed cost, and shipping is not included.
- "Reputable store" here means Robu, Robocraze, ThinkRobotics, Quartz Components, Evelta, ElectronicsComp, Indian Hobby Center (IHC) or Probots. IndustryBuying (IB) is used only when none of those had the part.

---

## A. Servos

### A1. Waveshare ST3215 / Feetech STS3215 / ST3215-HS

| Item | Product title (as listed) | Store | Price ₹ | GST incl.? | Stock | URL | Note |
|---|---|---|---|---|---|---|---|
| ST3215 7.4 V | Waveshare ST3215 Serial Bus Servo, 360° Encoder, 19.5kg.cm @ 7.4V (SKU R258500) | Robu | 2,159 | Yes | IN | https://robu.in/product/waveshare-st3215-serial-bus-servo/ | Confirms ₹2,159. Page text: "Torque:19.5kg.cm@7.4V", "Operating Voltage:4V ~ 7.4V", "0.192sec / 60°(52RPM)@7.4V", 1 Year Warranty. The page's `<title>` says "30kg.cm", which conflicts with the listing. |
| ST3215 7.4 V | ST3215 Series Serial Bus Servo, High precision and torque, 360 Degrees Magnetic Encoder, variant "19.5kg.cm@7.4V" (SKU WVSH0593) | ThinkRobotics | 2,399.99 | Not stated | IN | https://thinkrobotics.com/products/st3215-series-serial-bus-servo | Same page also has the 12 V variant (next row) |
| ST3215 12 V | same page, variant "30kg.cm@12V" (SKU WVSH0241) | ThinkRobotics | 2,649.99 | Not stated | IN | https://thinkrobotics.com/products/st3215-series-serial-bus-servo | – |
| ST3215 12 V | Waveshare 30KG Serial Bus Servo (SKU 1331215) | Robu | 2,599 | Yes | IN | https://robu.in/product/waveshare-30kg-serial-bus-servo/ | Listing text: "Model: ST3215 serial bus servo", "Operating voltage: 6 - 12V" |
| ST3215 12 V | Waveshare 360° 30KG Serial Servo with High Precision & Torque | Robocraze | 2,599 | Yes | IN | https://robocraze.com/products/waveshare-30kg-serial-servo-with-360-magnetic-encoder-high-precision | – |
| Feetech STS3215 7.4 V | ST3215 - 7.4V 19Kg 1/345 Gear Dual Axis TTL String Servo Motor (brand Feetech, MPN STS3215-C001) | Evelta | 2,224.30 (1,885.00 ex) | Yes (both shown) | IN (80) | https://evelta.com/st3215-7-4v-19kg-1-345-gear-dual-axis-ttl-string-servo-motor/ | Evelta spec block: 19.5kg.cm@6V, 6-7.4V, 55±1g, "Horn Gear Spline: 25T" (see spec section) |
| Feetech STS3215 7.4 V (other gear ratios) | STS3215-C046 - 7.4V 1:147 … / STS3215-C044 - 7.4V 1:191 86RPM … | Evelta | 2,224.30 each (1,885.00 ex) | Yes | IN (60) / IN (25) | https://evelta.com/sts3215-c046-7-4v-1-147-magnetic-encoding-metal-gear-dual-axis-ttl-serial-bus-servo-motor/ | Faster, lower-ratio variants. C044 URL: https://evelta.com/sts3215-c044-7-4v-1-191-86rpm-metal-gear-dual-axis-ttl-serial-bus-servo-motor/ |
| Feetech STS3215 12 V | ST3215-C018 - 12V 30kg·cm Dual-Shaft TTL Serial Servo, Metal Gears, Magnetic Encoder (brand Feetech) | Evelta | 2,419.00 (2,050.00 ex) | Yes | IN (61) | https://evelta.com/st3215-c018-12v-30kg-cm-dual-shaft-ttl-serial-servo-metal-gears-magnetic-encoder/ | Evelta spec: 30kg.cm@12V stall, 10kg.cm@12V rated, 4-14V, "25T/OD5.9mm" spline |
| ST3215-HS | Waveshare 20kg.cm Bus Servo Motor, 106PRM High Speed, Large Torque, With 360 Degrees High Precision Magnetic Encoder (SKU 1738071) | Robu | 2,529 | Yes | IN | https://robu.in/product/waveshare-20kg-cm-bus-servo-motor-106prm-high-speed-large-torque-with-360-degrees-high-precision-magnetic-encoder/ | Listing: "ST3215-HS", 6 to 12.6 V |
| ST3215-HS | ST3215-HS 20kg.cm Bus Servo Motor, 106PRM High Speed (SKU WVSH0244) | ThinkRobotics | 2,699.99 | Not stated | IN | https://thinkrobotics.com/products/st3215-hs | – |
| ST3215-HS | Waveshare 20kg·cm High-Torque Bus Servo Motor, 106RPM with 360° Magnetic Encoder | Robocraze | 2,529 | Yes | OOS | https://robocraze.com/products/waveshare-20kg-cm-high-torque-bus-servo-motor | – |

**Recommended picks**
- **ST3215 (7.4 V):** Robu, ₹2,159 incl. GST, in stock. Alternatives: Evelta Feetech STS3215-C001 ₹2,224.30 incl. (80 in stock); ThinkRobotics ₹2,399.99.
- **Feetech STS3215 (7.4 V):** Evelta STS3215-C001, ₹2,224.30 incl. GST (80 in stock). No other store checked lists it as a separate product; ThinkRobotics has it only inside the SO-101 arm kit.
- **12 V version:** Evelta Feetech ST3215-C018, ₹2,419.00 incl. GST (61 in stock). Waveshare 12 V: Robu or Robocraze, ₹2,599 incl.
- **ST3215-HS:** Robu, ₹2,529 incl. GST, in stock.

### A2. Cheaper serial-bus servos (arms / head)

| Item | Product title (as listed) | Store | Price ₹ | GST incl.? | Stock | URL | Note |
|---|---|---|---|---|---|---|---|
| Waveshare SC09 | Waveshare 2.3kg Dual-axis Serial Bus Servo, Two-way Feedback, Servo/Motor Mode Switchable, Compact Size, 300 Rotation Angle | ElectronicsComp | 985.30 calc (835.00 ex) | Ex | IN (1) | https://www.electronicscomp.com/waveshare-23kg-dual-axis-serial-bus-servo-two-way-feedback-servo-motor-mode-switchable-compact-size-300-rotation-angle | Only 1 unit in stock |
| Waveshare SC09 | Waveshare 2.3kg Dual-axis Serial Bus Servo … 300° Rotation Angle (second listing) | ElectronicsComp | 1,233.10 calc (1,045.00 ex) | Ex | IN (32) | https://www.electronicscomp.com/waveshare-2.3kg-dual-axis-serial-bus-servo-two-way-feedback-servo-motor-mode-switchable-compact-size-300-rotation-angle | – |
| Waveshare SC09 | Waveshare 2.3kg Dual-axis Serial Bus Servo, Two-way Feedback, Servo/Motor Mode Switchable, Compact Size, 300° Rotation Angle (SKU 1592663) | Robu | 1,088 | Yes | IN | https://robu.in/product/waveshare-2-3kg-dual-axis-serial-bus-servo/ | The product page description calls it "SC09 Servo". Robu text says "Wide voltage input 4.8-8.4V", but Waveshare says 4~6V (see spec section). |
| Feetech SCS0009 | SCS0009 - 6V 2.3kg 300deg Serial BUS Servo Motor (brand Feetech) | Evelta | 1,074.91 (910.94 ex) | Yes | IN (182) | https://evelta.com/scs0009-6v-2-3kg-300deg-serial-bus-servo-motor/ | Evelta: 2.3kg.cm@6V, 0.7kg.cm rated, 13.2±1g, spline 20T |
| Waveshare ST3020 | Waveshare 25kg.cm Wide Range Voltage Serial Bus Servo, High Precision And Large Torque, With Programmable 360 Degrees Magnetic Encoder (SKU 1738072) | Robu | 2,618 | Yes | IN | https://robu.in/product/waveshare-25kg-cm-wide-range-voltage-serial-bus-servo-high-precision-and-large-torque-with-programmable-360-degrees-magnetic-encoder/ | Listing: "Product Type: ST3020 serial bus servo", 6 to 14 V (typ. 12V), 25kg.cm@12V, 12-bit encoder. Not on Robocraze, ThinkRobotics, Quartz, Evelta or ElectronicsComp. |
| Feetech STS3020 (different product) | STS3020 - 7.4V 20kg.cm 360deg Copper Metal Gear Digital Servo Motor | Evelta | 2,426.73 (2,056.55 ex) | Yes | IN (5) | https://evelta.com/sts3020-7-4v-20kg-cm-360deg-copper-metal-gear-digital-servo-motor/ | Feetech part, not the Waveshare ST3020 |
| Waveshare ST3025 | Waveshare 40kg.cm Metal Serial Bus Servo with Brushless Motor & 360° Magnetic Encoder | Robocraze | 10,299 | Yes | IN | https://robocraze.com/products/waveshare-40kg-cm-metal-serial-bus-servo-with-brushless-motor | Not cheaper than ST3215 |
| Waveshare ST3025 | ST3025 40kg.cm Metal Serial Bus Servo, High Precision And Large Torque (SKU WVSH0243) | ThinkRobotics | 10,299.99 | Not stated | IN | https://thinkrobotics.com/products/40kg-cm-metal-serial-bus-servo-high-precision-and-large-torque | – |
| Waveshare ST3025 | Waveshare 40kg.cm Metal Serial Bus Servo … Brushless Motor (SKU 1738073) | Robu | 9,259 | Yes | OOS | https://robu.in/product/waveshare-40kg-cm-metal-serial-bus-servo-high-precision-and-large-torque-with-programmable-360-degrees-magnetic-encoder-and-brushless-motor/ | – |
| Feetech STS3032 | STS3032 - 6V 4.5kg 360deg Serial Bus Servo Motor | Evelta | 3,451.65 (2,925.13 ex) | Yes | OOS | https://evelta.com/sts3032-6v-4-5kg-360deg-serial-bus-servo-motor/ | Not found on Robu, Robocraze, ThinkRobotics or Quartz |
| Feetech ST-3032 | ST-3032-C001 - 6V 4.5kg.cm 360deg Metal Gear Single-Axis TTL Serial Bus Servo Motor | Evelta | 3,451.65 calc (2,925.13 ex) | Yes | IN (15) | https://evelta.com/st-3032-c001-6v-4-5kg-cm-360deg-metal-gear-single-axis-ttl-serial-bus-servo-motor/ | – |
| Feetech ST-3032 | ST-3032-C036 - 6V 4.5kg.cm 360deg Dual-Axis Metal Case Steel Gear Serial Bus Servo Motor | Evelta | 3,872.77 calc (3,282.01 ex) | Yes | IN (5) | https://evelta.com/st-3032-c036-6v-4-5kg-cm-360deg-dual-axis-metal-case-steel-gear-serial-bus-servo-m | URL is as shown in the Evelta search result (it looks truncated) |
| Hiwonder LX-16A | Hiwonder LX-16A Full Metal Gear Serial Bus Servo with Real-Time Feedback Function for RC Robot | ThinkRobotics | 2,099.99 | Not stated | IN | https://thinkrobotics.com/products/hiwonder-lx-16a-full-metal-gear-serial-bus-servo-with-real-time-feedback-function-for-rc-robot-control-angle-240 | Not found on Robu, Robocraze, Evelta or ElectronicsComp |
| Hiwonder LX-15D | Hiwonder LX-15D Intelligent Serial Bus Servo with RGB Indicator for Displaying Robot Status | ThinkRobotics | 2,899.99 | Not stated | IN | https://thinkrobotics.com/products/hiwonder-lx-15d-intelligent-serial-bus-servo-with-rgb-indicator-for-displaying-robot-status | – |
| Hiwonder LX-15D | same title (SKU R134529) | Robu | 2,809 | Yes | OOS | https://robu.in/product/hiwonder-lx-15d-intelligent-serial-bus-servo-with-rgb-indicator-for-displaying-robot-status/ | – |
| Hiwonder LX-224 | Hiwonder LX-224 Serial Bus Servo with Three Connectors /20KG Large Torque | ThinkRobotics | 2,899.99 | Not stated | IN | https://thinkrobotics.com/products/hiwonder-lx-224-serial-bus-servo-with-three-connectors-20kg-large-torque | – |
| Hiwonder LX-224HV | Hiwonder LX224 HV servo motor (SKU R140355) | Robu | 2,089 | Yes | IN | https://robu.in/product/hiwonder-lx224-hv-servo-motor/ | HV version. ThinkRobotics sells LX-224HV at ₹3,499.99 (IN). |
| (extra) Waveshare SC15 | Waveshare SC15 17kg Large Torque Programmable Serial Bus Servo (SKU 1219081) | Robu | 2,069 | Yes | IN | https://robu.in/product/waveshare-sc15-17kg-large-torque-programmable-serial-bus-servo/ | Listing: 4.8-8.4V, 180°/1024, 38400bps–1Mbps. ThinkRobotics ₹2,099.99 (IN). |

**Recommended picks**
- **SC09:** ElectronicsComp, ₹985.30 incl. (₹835 + 18% GST), but only 1 unit is in stock. For several units: Evelta Feetech SCS0009 ₹1,074.91 incl. (182 in stock) or Robu Waveshare SC09 ₹1,088 incl.
- **ST3020:** Robu, ₹2,618 incl. GST, in stock.
- **ST3025:** Robocraze, ₹10,299 incl. GST, in stock. This is about 4.8× the ST3215 price.
- **STS3032:** Evelta ST-3032-C001, ₹3,451.65 incl. (15 in stock). The plain STS3032 listing is out of stock.
- **LX-16A:** ThinkRobotics, ₹2,099.99 (GST not stated), in stock.
- **LX-15D:** ThinkRobotics, ₹2,899.99, in stock.
- **LX-224:** ThinkRobotics, ₹2,899.99, in stock. The HV version at Robu is ₹2,089 incl.
- **Price note:** none of the ST3020, ST3025, STS3032 or LX-series servos is cheaper than the Robu ST3215 at ₹2,159. Only the SC09/SCS0009 class, at about ₹985–1,088, is cheaper.

### A3. PWM servos (comparison)

| Item | Product title (as listed) | Store | Price ₹ | GST incl.? | Stock | URL | Note |
|---|---|---|---|---|---|---|---|
| MG90S | Tower Pro MG90S Servo Motor with Metal Gear | Quartz | 124 | Not stated | IN | https://quartzcomponents.com/products/tower-pro-mg90s-servo-motor-with-metal-gear | – |
| MG90S | TowerPro MG90S Mini Digital Servo Motor (180° Rotation)-Normal Quality (SKU 1308083) | Robu | 125 | Yes | IN | https://robu.in/product/towerpro-mg90s-mini-digital-servo-motor-180-rotation-standard-quality/ | Robu "High Quality" MG90S (SKU 23904) is ₹279 |
| MG90S | MG90S Mini Servo Motor (180 Degree) | Robocraze | 145 | Yes | IN | https://robocraze.com/products/mg90s-servo-motor | – |
| SG90 | Tower Pro SG90 Servo Motor - 9 gms Mini/Micro Servo Motor | Quartz | 86 | Not stated | IN | https://quartzcomponents.com/products/tower-pro-sg90-servo-9-gms-mini-micro-servo-motor | – |
| SG90 | TowerPro SG90 Mini Servo - 180 degree Rotation - Standard Quality (SKU 5764) | Robu | 89 | Yes | IN | https://robu.in/product/towerpro-sg90-9g-mini-servo-9-gram/ | "Good Quality" SG90 is ₹198 |
| SG90 | TowerPro SG90 9G Micro Servo Motor 180° for Arduino & Robotics | Robocraze | 99 | Yes | IN | https://robocraze.com/products/sg90-micro-servo-motor | – |
| MG996R | MG996R Tower Pro Digital Metal Gear High Torque Servo Motor (180 Degree Rotation) | Quartz | 259 | Not stated | IN | https://quartzcomponents.com/products/mg996 | Quartz 360° version ₹254 |
| MG996R | MG996R Metal Gear Servo Motor - 180 Degree | Robocraze | 399 | Yes | IN | https://robocraze.com/products/mg996r-servo-motor | – |
| MG996R | TowerPro MG996R Digital High Torque Servo Motor(180° Rotation) (SKU 1070680) | Robu | 409 | Yes | IN | https://robu.in/product/towardpro-mg996r-digital-high-torque-servo-motor/ | – |

**Recommended picks**
- **MG90S:** Quartz, ₹124, in stock.
- **SG90:** Quartz, ₹86, in stock.
- **MG996R:** Quartz, ₹259 (180°), in stock.

### A4. Serial-bus servo driver boards

| Item | Product title (as listed) | Store | Price ₹ | GST incl.? | Stock | URL | Note |
|---|---|---|---|---|---|---|---|
| Waveshare Bus Servo Adapter (A) | – | Robu, Robocraze, ThinkRobotics, Quartz, Evelta, ElectronicsComp | – | – | NOT FOUND | – | No listing with this name in any store searched |
| Waveshare Serial Bus Servo Driver Board | Serial Bus Servo Driver (SKU WVSH0166) | ThinkRobotics | 499.99 | Not stated | IN | https://thinkrobotics.com/products/serial-bus-servo-driver | Page: controls up to 253 ST/SC servos; "9~12.6V voltage input (the input voltage and the servo voltage must be matched)"; UART; 42.00 × 33.00 mm; mounting holes 2.50 mm at 37.00 × 28.00 mm |
| Waveshare Serial Bus Servo Driver Board | Waveshare Serial Bus Servo Driver Board, Integrates Servo Power Supply And Control Circuit, Applicable for ST/SC Series Serial Bus Servos (SKU 1782919) | Robu | 481 | Yes | OOS | https://robu.in/product/waveshare-serial-bus-servo-driver-board-integrates-servo-power-supply-and-control-circuit-applicable-for-st-sc-series-serial-bus-servos/ | – |
| Waveshare Serial Bus Servo Driver Board | same title | ElectronicsComp | 518.02 calc (439.00 ex) | Ex | OOS | https://www.electronicscomp.com/waveshare-serial-bus-servo-driver-board-integrates-servo-power-supply-and-control-circuit-applicable-for-st-sc-series-serial-bus-serv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 | – |
| Waveshare Serial Bus Servo Driver Board | Serial Bus Servo Driver Board 9~12.6V DC, Control up to 253 Servos | Evelta | 581.74 (493.00 ex) | Yes | OOS | https://evelta.com/serial-bus-servo-driver-board-9-12-6v-dc-control-up-to-253-servos/ | – |
| SmartElex serial bus servo driver | SmartElex Serial Bus Servo Driver Board, Integrates Servo Power Supply And Control Circuit (SKU R255565) | Robu | 509 | Yes | IN | https://robu.in/product/smartelex-serial-bus-servo-driver-board/ | Confirms ₹509. Listing: "253 servos control", "9–12.6V input", UART/USB. |
| SmartElex serial bus servo driver | SmartElex Serial Bus Servo Driver Board, Integrates Servo Power Supply and Control Circuit | Robocraze | 509 | Yes | IN | https://robocraze.com/products/smartelex-serial-bus-servo-driver-board-integrates-servo-power-supply-and-control-circuit | – |
| (related) 7.2 V buck for bus servos | Waveshare Serial Bus Servo DC Buck Adapter, Mini Module, Design for Serial Bus Servos, Easy to Use, 7.2V Buck Regulator (SKU R136622) | Robu | 479 | Yes | IN | https://robu.in/product/waveshare-serial-bus-servo-dc-buck-adapter-mini-module-design-for-serial-bus-servos-easy-to-use-7-2v-buck-regulator/ | ElectronicsComp lists it at ₹334 ex (stock not checked): https://www.electronicscomp.com/waveshare-serial-bus-servo-dc-buck-adapter-mini-module-design-for-serial-bus-servos-easy-to-use-72v-buck-regulator |
| (related) Feetech USB programmer | FE-URT-1 - RS485 Servo Bus Programmer, USB to TTL Serial Signal Converter | Evelta | 1,249.90 calc (1,059.24 ex) | Yes | IN (2) | https://evelta.com/fe-urt-1-rs485-servo-bus-programmer-usb-to-ttl-serial-signal-converter/ | – |
| (related) ESP32 driver board | Waveshare ESP32-Based General Driver board for Robots supports Wi-Fi & Bluetooth | Robocraze | 3,178 | Yes | IN | https://robocraze.com/products/waveshare-esp32-based-general-driver-board-for-robots-supports-wi-fi-bluetooth | Robocraze listing says it controls up to 253 ST3215 servos. ThinkRobotics ₹3,249.99. |

**Recommended pick**
- ThinkRobotics Waveshare Serial Bus Servo Driver, ₹499.99 (GST not stated), in stock.
- Alternative: SmartElex board, ₹509 incl. GST, at Robu or Robocraze, both in stock.
- Voltage flag (not tested): both boards list 9–12.6 V input, and Waveshare says the input voltage "must be matched" to the servo voltage. Check this before pairing them with 7.4 V ST3215 servos on a 2S pack.

---

## B. Compute

| Item | Product title (as listed) | Store | Price ₹ | GST incl.? | Stock | URL | Note |
|---|---|---|---|---|---|---|---|
| Raspberry Pi 5 4GB | Raspberry PI 5 Model B BCM2712 Arm Cortex-A76 4GB RAM 2.4GHZ Single Board Computer (SKU PRO4729) | Probots | 15,949 | Yes (13,516.10 + 2,432.90 GST) | IN | https://probots.co.in/raspberry-pi-5-model-b-bcm2712-arm-cortex-a76-4gb-ram-2-4ghz-single-board-computer.html | Only in-stock 4 GB found |
| Raspberry Pi 5 4GB | Raspberry Pi 5 Model 4GB RAM (SKU 1749032) | Robu | 13,409 | Yes | OOS | https://robu.in/product/raspberry-pi-5-model-4gb/ | Robu "Official Raspberry Pi 5 4GB Starter Kit" ₹16,149 is also OOS |
| Raspberry Pi 5 4GB | Raspberry Pi 5, variant 4GB (SKU SBC1067-4) | ThinkRobotics | 16,199.99 | Not stated | OOS | https://thinkrobotics.com/products/raspberry-pi-5 | – |
| Raspberry Pi 5 4GB | Raspberry Pi 5 Model with 4GB Ram | ElectronicsComp | 15,574.82 calc (13,199.00 ex) | Ex | OOS | https://www.electronicscomp.com/raspberry-pi-5-model-4gb | – |
| Raspberry Pi 5 8GB | Raspberry Pi 5 Model 8GB RAM (SKU 1749034) | Robu | 19,999 | Yes | IN | https://robu.in/product/raspberry-pi-5-model-8gb/ | – |
| Raspberry Pi 5 8GB | Raspberry Pi 5, variant 8GB (SKU SBC1067-8) | ThinkRobotics | 19,999.99 | Not stated | IN | https://thinkrobotics.com/products/raspberry-pi-5 | – |
| Raspberry Pi 4 2GB | Raspberry Pi 4 Model B, variant "2GB with Case" (SKU SBC1010) | ThinkRobotics | 6,999.99 | Not stated | IN | https://thinkrobotics.com/products/raspberry-pi-4-model-b | Variant includes a case |
| Raspberry Pi 4 2GB | Raspberry Pi 4 Model B with 2GB RAM (SKU 471148) | Robu | 6,449 | Yes | OOS | https://robu.in/product/raspberry-pi-4-model-b-with-2-gb-ram/ | – |
| Raspberry Pi 4 2GB | Raspberry Pi 4 Model B with 2GB Ram (Latest & Original) | ElectronicsComp | 9,379.82 calc (7,949.00 ex) | Ex | IN (4) | https://www.electronicscomp.com/raspberry-pi-4-model-b-with-2-gb-ram-india | – |
| Raspberry Pi 4 4GB | Raspberry Pi 4 Model B - 4GB RAM | Quartz | 9,695 | Not stated | IN | https://quartzcomponents.com/products/raspberry-pi-4-model-b-4-gb-ram | – |
| Raspberry Pi 4 4GB | Official Raspberry Pi 4 Model B 4GB RAM Development Board | Robocraze | 11,465 | Yes | IN | https://robocraze.com/products/raspberry-pi-4-model-b-4gb-ram | – |
| Raspberry Pi 4 4GB | Raspberry Pi 4 Model B with 4GB RAM (SKU 471149) | Robu | 11,469 | Yes | IN | https://robu.in/product/raspberry-pi-4-model-b-with-4-gb-ram/ | ThinkRobotics 4GB variant ₹12,449.99 (IN) |
| Raspberry Pi Zero 2 W | Raspberry Pi Zero 2 W (SKU 1124637) | Robu | 2,079 | Yes | OOS | https://robu.in/product/raspberry-pi-zero-2-w/ | – |
| Raspberry Pi Zero 2 W | Raspberry Pi Zero 2 W | Evelta | 1,748.76 (1,482.00 ex) | Yes | OOS (schema OutOfStock) | https://evelta.com/raspberry-pi-zero-2-w/ | – |
| Raspberry Pi Zero 2 W | Raspberry Pi Zero 2 W | ElectronicsComp | 2,358.82 calc (1,999.00 ex) | Ex | OOS | https://www.electronicscomp.com/raspberry-pi-zero-2-w-india | – |
| Raspberry Pi Zero 2 W | Raspberry Pi Zero 2W (SKU AI5307) | Zbotic | 1,648.46 (1,397.00 + GST) | Yes | OOS | https://zbotic.in/?s=raspberry+pi+zero+2+w&post_type=product | Search page |
| Raspberry Pi Zero 2 W | Raspberry Pi Zero 2W | Hubtronics | 2,360 (2,000 ex) | Yes | OOS ("Notify when available") | https://hubtronics.in/index.php?route=product/search&search=zero%202%20w | Search page |
| Official Pi 5 27 W PSU | Official 27W USB-C PD Power Supply for Raspberry Pi 5 - Black | Quartz | 1,063 | Not stated | IN | https://quartzcomponents.com/products/official-27w-usb-c-pd-power-supply-for-raspberry-pi-5-white-black | – |
| Official Pi 5 27 W PSU | Official Raspberry Pi 5 27W USB-C PD Power Supply (Black) | Robocraze | 1,204 | Yes | IN | https://robocraze.com/products/raspberry-pi-5-27w-usb-c-power-supply-black-colour | White version ₹1,255 |
| Official Pi 5 27 W PSU | Official 27W USB-C PD Power Supply for Raspberry Pi 5 - Black(Plug Type :IN) (SKU 1749014) | Robu | 1,255 | Yes | IN | https://robu.in/product/official-27w-usb-c-pd-power-supply-for-raspberry-pi-5-black/ | Evelta ₹1,091.50 incl. is OOS |
| Pi 5 Active Cooler | Official Raspberry Pi 5 Active Cooler Fan | Quartz | 438 | Not stated | IN | https://quartzcomponents.com/products/official-raspberry-pi-5-active-cooler | – |
| Pi 5 Active Cooler | Official Raspberry Pi 5 Active Cooler (SKU 1749017) | Robu | 519 | Yes | IN | https://robu.in/product/official-raspberry-pi-5-active-cooler/ | – |
| Pi 5 Active Cooler | Raspberry Pi 5 Active Cooler | Robocraze | 522 | Yes | IN | https://robocraze.com/products/raspberry-pi-active-cooler | Evelta ₹460.20 incl. is OOS |
| SanDisk 32 GB microSD | SanDisk Ultra Micro SD 32GB UHS-I, 120MB/s R , Class 10 Memory Card | Quartz | 1,499 | Not stated | IN | https://quartzcomponents.com/products/32gb-ultra-microsd-memory-card-red-grey | Description: "Class 10, UHS-I, A1" |
| SanDisk 32 GB microSD | SanDisk Ultra GO micro SDHC 32GB UHS-I, 120MB/s R , Class 10 Memory Card (SKU R268040) | Robu | 1,629 | Yes | IN | https://robu.in/product/sandisk-ultra-go-micro-sdhc-32gb-uhs-i-120mbs-r-class-10-memory-card/ | A1/A2 class not in title. Robu SanDisk Ultra 32GB (SKU 544645) ₹1,519 is OOS. |
| SanDisk 32 GB microSD | SanDisk 32GB Micro SDHC Memory Card Class 10 A1 for Raspberry Pi | Robocraze | 1,549 | Yes | OOS | https://robocraze.com/products/sandisk-32gb-micro-sd-sdhc-card | – |
| 32 GB microSD A2 (not SanDisk) | Official Raspberry Pi 32GB Micro SD Card A2 Class | ThinkRobotics | 1,479.99 | Not stated | IN | https://thinkrobotics.com/products/official-raspberry-pi-32gb-micro-sd-card-a2-class-unprogrammed | Excluded: ThinkRobotics "SanDisk Extreme SDHC 90MBPS 32GB" (₹1,299.99) is a full-size SD card per its description, not microSD |

**Recommended picks**
- **Pi 5 4GB:** Probots, ₹15,949 incl. GST, in stock. It is out of stock at Robu, ThinkRobotics and ElectronicsComp.
- **Pi 5 8GB:** Robu, ₹19,999 incl. GST, in stock.
- **Pi 4 2GB:** ThinkRobotics "2GB with Case", ₹6,999.99, in stock.
- **Pi 4 4GB:** Quartz, ₹9,695, in stock.
- **Pi Zero 2 W:** no in-stock listing in any of 5 stores (Robu, Evelta, ElectronicsComp, Zbotic, Hubtronics). The lowest listed price is Zbotic ₹1,648.46 incl. (OOS).
- **27 W PSU:** Quartz, ₹1,063, in stock.
- **Active Cooler:** Quartz, ₹438, in stock.
- **SanDisk 32 GB microSD:** Quartz SanDisk Ultra A1, ₹1,499, in stock. The cheapest A2 card found is the non-SanDisk ThinkRobotics official Raspberry Pi card at ₹1,479.99.

---

## C. IMU breakouts

| Item | Product title (as listed) | Store | Price ₹ | GST incl.? | Stock | URL | Note |
|---|---|---|---|---|---|---|---|
| MPU6050 | MPU6050 3-Axis Gyroscope/Accelerometer Sensor Module | Quartz | 127 | Not stated | IN | https://quartzcomponents.com/products/mpu6050-gyroscope-accelerometer-sensor | – |
| MPU6050 | MPU-6050 Triple-Axis Accelerometer & Gyroscope Module | Robocraze | 154 | Yes | IN | https://robocraze.com/products/mpu-6050-triple-axis-accelerometer-gyroscope-module | – |
| MPU6050 | SmartElex MPU-6050 3-Axis Accelerometer and Gyro Sensor Module (SKU R268095) | Robu | 444 | Yes | IN | https://robu.in/product/smartelex-mpu-6050-3-axis-accelerometer-and-gyro-sensor-module/ | Robu generic MPU-6050 (SKU 2846) ₹159 is OOS |
| BNO055 | 7Semi BNO055 9-DOF Absolute Orientation Sensor Breakout I2C Qwiic | Evelta | 1,341.66 (1,137.00 ex) | Yes | IN (392) | https://evelta.com/7semi-bno055-9-dof-absolute-orientation-sensor-breakout-i2c-qwiic/ | – |
| BNO055 | BNO055 9-DOF Absolute Orientation Sensor | ThinkRobotics | 1,349.99 | Not stated | IN | https://thinkrobotics.com/products/9-dof-absolute-orientation-bno055-sensor | – |
| BNO055 | BNO055 9-DOF Absolute Orientation Sensor Breakout with I2C Qwiic - 7Semi | Robocraze | 1,359 | Yes | IN | https://robocraze.com/products/bno055-9-dof-absolute-orientation-sensor-breakout-with-i2c-qwiic-7semi | Robu "Bosch BNO055, 9-Axis…" (SKU R231480) ₹1,439 IN |
| BNO085 | 7Semi BNO085 9-DOF Orientation IMU Fusion Nano Breakout | Evelta | 2,094.50 (1,775.00 ex) | Yes | IN (21) | https://evelta.com/7semi-bno085-9-dof-orientation-imu-fusion-nano-breakout/ | – |
| BNO085 | BNO085 9-DOF Orientation IMU Sensor Fusion Nano Breakout Board | Robocraze | 2,095 | Yes | IN | https://robocraze.com/products/bno085-9-dof-orientation-imu-sensor-fusion-nano-breakout-board | – |
| BNO085 | SmartElex 9-DOF Orientation IMU Fusion Breakout - BNO085 (SKU R268085) | Robu | 2,409 | Yes | IN | https://robu.in/product/smartelex-9-dof-orientation-imu-fusion-breakout-bno085/ | Adafruit BNO085 at Robu ₹4,299 IN |
| ICM-20948 | ICM-20948 9DoF IMU Breakout Board (MPU-9250 Upgrade) - 7Semi | Robocraze | 1,130 | Yes | IN | https://robocraze.com/products/icm-20948-9dof-imu-breakout-board-mpu-9250-upgrade-7semi | Not on ThinkRobotics or Quartz |
| ICM-20948 | SparkFun SEN-15335 9DoF IMU Breakout - ICM-20948 (SKU 637310) | Robu | 2,959 | Yes | IN | https://robu.in/product/sparkfun-9dof-imu-m0-razor-breakout-board-with-micro-sd-card-socket/ | URL slug differs from the title (as listed) |
| ICM-20948 | ICM-20948 Low Power 9 Axis MEMS Motion Tracking Device Sensor (SKU R263837) | Robu | 789 | Yes | OOS | https://robu.in/product/icm-20948-low-power-9-axis-mems-motion-tracking-device-sensor/ | – |

**Recommended picks**
- **MPU6050:** Quartz, ₹127, in stock.
- **BNO055:** Evelta 7Semi, ₹1,341.66 incl. (392 in stock).
- **BNO085:** Evelta 7Semi Nano, ₹2,094.50 incl. (21 in stock). Robocraze has it at ₹2,095 incl.
- **ICM-20948:** Robocraze 7Semi, ₹1,130 incl., in stock.

---
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

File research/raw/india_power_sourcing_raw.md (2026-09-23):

# JX1 power-system sourcing: India (raw research log)

- **Date of all checks:** 2026-09-24 (IST). Researcher: power-system sourcing agent (r5). Status: **complete first pass.**
- **Scope:** cells, packs, BMS, protection, DC-DC, connectors/wire/chargers, battery-safety consumables for JX1 (1.2 m, 25–30 kg, 20–24 BLDC joints, 24 V or 36–48 V bus, 150–400 W average, 1.5–3 kW peaks lasting under 1 s).
- Scratch data (raw JSONL dumps of every store query) is in the session scratchpad `…/scratchpad/r5/` (`results.jsonl`, `woo.jsonl`, `rk*.jsonl`, `oc*.jsonl`, `mog.jsonl`, `ib.jsonl`, `ev.jsonl`, `pages/`).

## 0. Evidence labels, GST basis, coverage

- **VERIFIED**: price and stock read on 2026-09-24 from the live product page, or from the store's own product API (Shopify `suggest.json` / `products/<h>.js`, WooCommerce Store API, JSON-LD on page), with the URL given.
- **ESTIMATED**: a derived number, with the math shown (incl-GST = ex-GST × 1.18; ₹/Wh = incl-GST price ÷ (V_nom × Ah)).
- **UNVERIFIED**: a lead only. This covers IndiaMART and search-engine snippets, prices hidden or shown as placeholders, and blocked stores.
- **GST basis by store** (checked on-site):
  - **robokits.co.in: EXCL GST.** The FAQ says "product price does not include taxes, handling & shipping charges", and product pages show "GST Input Tax Credit @ 18 %". For example, the ₹308 50S lists ITC ₹55.44 = 308 × 0.18.
  - **electronicscomp.com (EC): EXCL GST.** The price line reads "Rs.xxx (Excluding 18% GST)". The "(Inclusive of all Taxes)" figure on the same page is the MRP, not the selling price.
  - **lionbattery.in (LB): EXCL GST** ("Price Excluding Tax"). Its ex-GST figures are round incl-GST prices ÷ 1.18, e.g. 550.85 × 1.18 = 650.00.
  - **evelta.com: EXCL GST** (BigCommerce `price--withoutTax`).
  - **Incl GST:**
    - robocraze.com ("Incl. GST (No Hidden Charges)")
    - indianhobbycenter.com (IHC, "Taxes included")
    - moglix.com and industrybuying.com (IB): "(Incl. of all taxes)" with an ex + 18 % split shown
    - tanotis.com ("Includes all taxes … includes GST and import duties")
    - technobotix.in ("Price including GST")
    - indianrobostore.com (IRS, "(Inc GST)")
    - zbotic.in (shows "₹494.42 (₹419.00 + GST)")
  - **Not stated on product page ("n/s")**: quartzcomponents.com, thinkrobotics.com, kitsguru.com, thebatteryworld.in (TBW), batterysource.in. Indian B2C listings are normally GST-inclusive, but treat these as UNVERIFIED on tax.
- Li-ion cells and packs, BMS and electronics attract 18 % GST (Robokits cell pages show "GST ITC @ 18 %").
- **Not read:**
  - Skipped by instruction: robu.in, amazon.in, in.element14.com, digikey.in.
  - Blocked: tme.com/in (Cloudflare 403) and mouser.in ("Access denied" to automation). flyrobo.in returned 403.
  - probots.co.in: the Magento search redirects and was not parsed.
  - IndiaMART search is JS-rendered, so only snippet leads are included.
  - evelta.com search is fuzzy: it returned no Mean Well, contactors or ANL fuses, but did return JST-GH, TVS and capacitor parts.
- **WebSearch budget was exhausted mid-task.** Every later lead comes from each store's own on-site catalogue search, not a web search.

---

## TOP PICKS (best credible value, 2026-09-24)

| Need | Pick | Supplier | Price (incl GST) | ₹/Wh | Evidence |
|---|---|---|---|---|---|
| High-drain 21700 (cheapest credible) | Samsung INR21700-50S (5.0 Ah, 25 A / 45 A @80 °C cut) | Robokits | ₹363.44 (₹308 + GST) | 20.2 | VERIFIED, In Stock |
| High-drain 21700 (authorised channel) | Molicel INR-21700-P42A | The Battery World (authorised Molicel distributor) | ₹332.50 (GST n/s) | 22.0 (26.0 if +GST) | VERIFIED, In Stock |
| High-drain 21700 (best power) | Molicel P45B (45 A, DCR ≤13.8 mΩ) | Robokits | ₹481.44 (₹408 + GST) | 29.7 | VERIFIED, In Stock |
| High-drain 21700 (deep stock) | Molicel P45B | ElectronicsComp | ₹535.72 (₹454 + GST) | 33.1 | VERIFIED, 314 pcs |
| Budget 6S2P pack (low C) | DMEGC 6S2P 9 Ah 3C | lionbattery.in | ₹4,999 (₹4,236.44 + GST) | 25.0 | VERIFIED, 200 in stock |
| High-drain 6S2P pack | Crocks Pack Samsung 50S 6S2P 10 Ah 90 A | lionbattery.in | ₹8,500 (₹7,203.39 + GST) | 38.3 | VERIFIED, in stock |
| 6S LiPo 5–10 Ah | GenX 22.2 V 6S 10000 mAh 25C | IHC ₹10,319 / Robokits ₹9,088 + GST | ₹10,319 / ₹10,724 | 46.5 / 48.3 | VERIFIED, in stock |
| 13S 48 V pack (low C) | BAK 13S2P 48 V 10 Ah 3C | lionbattery.in | ₹10,560 (₹8,949.15 + GST) | 22.6 | VERIFIED, in stock |
| 13S smart BMS | JBD SP14S004 10–14S 40 A smart | lionbattery.in | ₹2,199 (₹1,863.56 + GST) | – | VERIFIED, 10 in stock |
| 6S/7S hardware BMS | Daly 6S 30 A / 7S 40 A waterproof | Quartz | ₹937 / ₹978 (GST n/s) | – | VERIFIED, available |
| E-stop 22 mm, twist-release | Schneider XB2BS8442C (40 mm, 1NC) | Moglix | ₹399 | – | VERIFIED, In stock |
| E-stop 1NO+1NC | Schneider XB5AS8445N (40 mm, trigger, turn-to-release) | Moglix | ₹789 | – | VERIFIED, In stock |
| MOSFET main switch | Flipsky Anti-Spark Switch Smart Enhanced 300A V2.0 (12–84 V, 100 A cont.) | technobotix.in | ₹7,499 | – | VERIFIED, In stock |
| 48 V → 5/12/19 V (non-isolated) | "48V 36V 24V to 19V 12V 9V 5V 3V" synchronous buck, 6.5–60 V in, 10 A | ElectronicsComp | ₹447.22 (₹379 + GST) | – | VERIFIED, 8 pcs |
| Isolated 48 V → 5 V (Jetson) | Mean Well DDR-60L-5 (5 V 10.8 A, 18–75 V in) | IndustryBuying | ₹4,247 | – | VERIFIED, "ships within 15 days" |
| Main connectors | Amass XT90-S pair (anti-spark) | Robokits | ₹212.40 (₹180 + GST) | – | VERIFIED, In Stock |

---

## 1. CELLS

### 1a. 21700 high-drain cells

| Item | Brand/Model | Supplier | Price ₹ | GST | Stock | Key specs (as listed) | ₹/Wh incl (EST) | URL | Date | Evidence |
|---|---|---|---|---|---|---|---|---|---|---|
| 21700 cell | Samsung INR21700-50S | Robokits | 308.00 (→363.44) | excl | In Stock | 5.0 Ah, 3.6 V, 25 A no temp cut / 45 A with 80 °C cut, ~72 g; reviewer measured 69 g, 9.97 mΩ @1 kHz | 20.19 | https://robokits.co.in/batteries-chargers/samsung-premium-li-ion-battery/3.7v-samsung-li-ion-batteries/samsung-21700-5000mah-inr21700-50s-45a-9c-li-ion-battery-origi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 | 2026-09-24 | VERIFIED |
| 21700 cell | Samsung INR21700-50S (Original) | lionbattery.in | 550.85 (→650.00) | excl | 27 in stock | 5.0 Ah, 45 A, 70 g, "Genuine Samsung SDI" (seller claim) | 36.11 | https://lionbattery.in/shop/shop/lithium-cells/li-ion-cylindrical-battery-cell/samsung-inr21700-50s-3-6v-5000mah-45a-li-ion-battery-original/ | 2026-09-24 | VERIFIED |
| 21700 cell | Molicel INR-21700-P42A | The Battery World (**authorised Molicel distributor**) | 332.50 (reg 350) | n/s | In Stock (og:availability) | 4.2 Ah, "30–45 A" (listing), NCA | 21.99 (25.95 if +GST) | https://www.thebatteryworld.in/products/molicel-inr-21700-p42a-3-6v-4200mah | 2026-09-24 | VERIFIED |
| 21700 cell | Molicel P42A | Robokits | 356.00 (→420.08) | excl | In Stock | 4.2 Ah, 35 A (listing), 67 g; "graded and tested…testing marks" | 27.78 | https://robokits.co.in/batteries-chargers/li-ion-cells/3.6v-21700-li-ion-cell/molicel-3.6v-4200mah-11c-lithium-ion-battery-original-inr21700-p42a-original | 2026-09-24 | VERIFIED |
| 21700 cell | Molicel P42A | Indian Hobby Center | 449.00 | incl | Available | 4.2 Ah, 45 A, 70 g | 29.70 | https://indianhobbycenter.com/products/molicel-inr-21700-p42a-3-6v-4200mah-11c-li-ion-battery | 2026-09-24 | VERIFIED |
| 21700 cell | Molicel P42A | Indian Robo Store | 479 (MRP 699) | incl | **Pre-order** | 4.2 Ah 11C | 31.68 | https://indianrobostore.com/product/molicel-a-grade-inr-21700-p42a-36v-4200mah-11c-li-ion-battery | 2026-09-24 | VERIFIED |
| 21700 cell | Molicel P42A | ElectronicsComp (listing A) | 419.00 (→494.42) | excl | **Out of stock** | 4.2 Ah 11C | 32.70 | https://www.electronicscomp.com/molicel-inr-21700-p42a-36v-4200mah-11c-li-ion-battery | 2026-09-24 | VERIFIED |
| 21700 cell | Molicel P42A | ElectronicsComp (listing B) | 615.00 (→725.70) | excl | 839 pcs | 4.2 Ah 11C | 48.00 | https://www.electronicscomp.com/molicel-inr21700-p42a-4200mah-11c-lithium-ion-battery | 2026-09-24 | VERIFIED |
| 21700 cell | Molicel P42A | batterysource.in | 560 (1 pc) / 2,360 (5 pc = 472 ea) | n/s | in stock | 4.2 Ah 11C | 37.0 / 31.2 | https://batterysource.in/product/molicel-inr-21700-p42a-3-6v-4200mah-11c-li-ion-battery/ | 2026-09-24 | VERIFIED (Woo API variants) |
| 21700 cell | Molicel P42A | Zbotic | 494.42 (419 + GST) | incl | Out of stock | URL slug embeds "IS 16046 (Part 2) R-41137189" (BIS mark) | 32.70 | https://zbotic.in/product/sealed-secondary-portable-lithiumion-cell-is-16046-part-2-r-41137189-3-6v-4-2ah-15-1w-h/ | 2026-09-24 | VERIFIED |
| 21700 cell | Molicel P42A | olelectronics.in | 457 | n/s | Out of stock | – | 30.2 | https://olelectronics.in/product/molicel-agrade-inr-21700-p42a-3-6v4200mah/ | 2026-09-24 | VERIFIED |
| 21700 cell | Molicel INR-21700-P45B | Robokits | 408.00 (→481.44) | excl | In Stock | 4.5 Ah, 45 A, "22 % lower DCR than P42A", 3C charge | 29.72 | https://robokits.co.in/batteries-chargers/li-ion-cells/3.7v-21700-li-ion-cell/molicel-4500mah-10c-lithium-ion-battery-inr21700-p45b | 2026-09-24 | VERIFIED |
| 21700 cell | Molicel P45B | ElectronicsComp | 454.00 (→535.72) | excl | 314 pcs | 4.5 Ah 10C | 33.07 | https://www.electronicscomp.com/molicel-inr21700-p45b-4500mah-10c-lithium-ion-battery | 2026-09-24 | VERIFIED |
| 21700 cell | Molicel P45B | Indian Hobby Center | 599.00 | incl | Available | 4.5 Ah, 45 A, 70 g, 242 Wh/kg | 36.98 | https://indianhobbycenter.com/products/molicel-inr-21700-p45b-3-6v-4500mah-10c-li-ion-battery | 2026-09-24 | VERIFIED |
| 21700 cell | Molicel P45B | Zbotic / OL Electronics / ThingBits | 516 / 477 / 500 | incl / n/s / "…of GST" | all **Out of stock** | – | – | https://zbotic.in/product/molicel-a-grade-inr-21700-p45b-3-6v-4500mah-10c-li-ion-battery/ ; https://olelectronics.in/product/molicel-agrade-inr-21700-p45b3-6v4500mah/ ; https://www.thingbits.in/products/molicel-inr21700-p45b-3-6v-4500-mah-lithium-ion-rechargeable-battery | 2026-09-24 | VERIFIED |
| 21700 cell | Molicel INR-21700-P50B | Robokits | 583.00 (→687.94) | excl | In Stock | 5.0 Ah, 60 A (80 °C cut-off), ≤70 g, origin "Canada or Taiwan" | 38.22 | https://robokits.co.in/batteries-chargers/li-ion-cells/3.7v-21700-li-ion-cell/molicel-21700-p50b-5000mah-60a-lithium-ion-battery | 2026-09-24 | VERIFIED |
| 21700 cell | Molicel P50B | Indian Hobby Center | 849.00 | incl | Available | 5.0 Ah 12C (60 A) | 47.17 | https://indianhobbycenter.com/products/molicel-inr-21700-p50b-3-6v-5000mah-12c-li-ion-battery-60a | 2026-09-24 | VERIFIED |
| 21700 cell | Samsung INR21700-40T | ElectronicsComp | 879.00 (→1,037) | excl | 64 pcs | **Seller states it is a COPY**: "Brand Generic, Country of Origin China… marking them as a copy" | 72.0 | https://www.electronicscomp.com/samsung-inr21700-40t-4000mah-9c-li-ion-battery | 2026-09-24 | VERIFIED (counterfeit disclosed) |
| 21700 cell | Samsung 40T | olelectronics.in | 901 | n/s | Out of stock | – | – | https://olelectronics.in/product/samsung-inr21700-40t-4000mah/ | 2026-09-24 | VERIFIED |
| 21700 cell | Samsung 50E / 40T, LG M50LT | batterysource.in | "₹110" in schema = **placeholder**; page shows no price ("Request for Bulk Orders") | n/s | n/a | – | – | https://batterysource.in/product/samsung-inr21700-50e-3-6v-5000mah-li-ion-battery/ | 2026-09-24 | UNVERIFIED (RFQ) |
| 21700 cell | LG INR21700 M50LT (4.8 Ah 1C) | olelectronics.in | 553 | n/s | Out of stock | energy cell, not high drain | – | https://olelectronics.in/product/lg-inr21700-m50lt-3-6v-4800mah/ | 2026-09-24 | VERIFIED |
| 21700 cell | LG INR21700H40 / H30 | ElectronicsComp | 879 / 791 | excl | Out of stock | – | – | https://www.electronicscomp.com/lg-inr21700h40-4000mah-9c-li-ion-battery | 2026-09-24 | VERIFIED |
| 21700 cell | Samsung INR21700-50G (2C) | ElectronicsComp | 1,229 (→1,450) | excl | 45 pcs | energy cell, very expensive | 80.6 | https://www.electronicscomp.com/samsung-inr21700-50g-5000mah-2c-li-ion-battery | 2026-09-24 | VERIFIED |
| EVE 40PL/50E, BAK 45A/45D, Lishen, LG M58T | – | not found in readable Indian stores | – | – | – | – | – | – | 2026-09-24 | NOT FOUND |

### 1b. 21700 "budget/energy" cells (3C or less: not for peak power)

| Item | Brand/Model | Supplier | Price ₹ | GST | Stock | Key specs | ₹/Wh incl (EST) | URL | Date | Evidence |
|---|---|---|---|---|---|---|---|---|---|---|
| 21700 | DMEGC INR21700-45E | ElectronicsComp | 233 (→274.94) | excl | 88 | 4.5 Ah, 3C | 16.97 | https://www.electronicscomp.com/dmegc-inr21700-45e-37v-4500mah-li-ion-battery | 2026-09-24 | VERIFIED |
| 21700 | DMEGC INR21700-45E "Original" | Quartz | 245 | n/s | available | 4.5 Ah, 3C, charge 1C | 15.12 (17.85 if +GST) | https://quartzcomponents.com/products/dmegc-inr-21700-li-ion-4500mah-3-7v-4500mah-rechargable-battery-original | 2026-09-24 | VERIFIED |
| 21700 | DMEGC 45E | lionbattery.in | 351.69 (→415) | excl | 200 in stock | 4.5 Ah | 25.62 | https://lionbattery.in/shop/shop/lithium-cells/li-ion-cylindrical-battery-cell/dmegc-inr18650-45e-3-7v-4500mah-li-ion-battery/ | 2026-09-24 | VERIFIED |
| 21700 | "CJ/Winway" 21700 "5000 mAh" | Quartz | 225 | n/s | available | **listing admits actual 4500 mAh, 1C** | 13.9 | https://quartzcomponents.com/products/21700-li-ion-3-7v-5000mah-3c-rechargeable-battery-winway | 2026-09-24 | VERIFIED (capacity inflated) |
| 21700 | BAK NMC 21700 5000 mAh 3C | ElectronicsComp | 448 (→528.64) | excl | 930 | 5 Ah 3C | 29.37 | https://www.electronicscomp.com/bak-nmc-21700-5000mah-3c-lithium-ion-36v-battery | 2026-09-24 | VERIFIED |
| 21700 | HEB ICR-21700 "6800 mAh" | ElectronicsComp | 489 | excl | 8 | **6.8 Ah in 21700 is not credible** (best commercial 21700s are about 5.8 Ah, e.g. LG M58T) | – | https://www.electronicscomp.com/heb-3.7v-6800mah-icr-21700-li-ion-high-energy-rechargeable-battery | 2026-09-24 | VERIFIED (**fake-capacity flag**) |

### 1c. 18650 cells

| Item | Brand/Model | Supplier | Price ₹ | GST | Stock | Key specs | ₹/Wh incl (EST) | URL | Date | Evidence |
|---|---|---|---|---|---|---|---|---|---|---|
| 18650 | Molicel INR-18650-P30B | The Battery World (authorised) | 320 | n/s | "Fresh Stock Arrived" | 3.0 Ah | 29.6 (35.0 if +GST) | https://www.thebatteryworld.in/category/li-ion-rechargeable-batteries | 2026-09-24 | VERIFIED (category page) |
| 18650 | Molicel P30B | Robokits | 316 (→372.88) | excl | In Stock | 3.0 Ah (min 2.9), 30 A cont. (80 °C cut-off), 36 A max; DC IR 17 mΩ @50 % SOC, AC 8 mΩ @30 % SOC (datasheet copy) | 34.53 | https://robokits.co.in/batteries-chargers/li-ion-cells/3.7v-18650-li-ion-cell/molicel-18650mah-13c-lithium-ion-battery-original-inr-18650-p30b | 2026-09-24 | VERIFIED |
| 18650 | Molicel P30B | ElectronicsComp / IHC | 539 (excl) / 599 (incl) | – | 45 / available | 3.0 Ah 10C | 58.9 / 55.5 | https://www.electronicscomp.com/molicel-inr-18650-p30b-36v-3000mah-10c-li-ion-battery ; https://indianhobbycenter.com/products/molicel-inr-18650-p30b-3-6v-2850mah-10c-li-ion-battery | 2026-09-24 | VERIFIED |
| 18650 | Molicel P28A | ElectronicsComp | 382 (→450.76) | excl | 274 | 2.8 Ah 13C | 44.72 | https://www.electronicscomp.com/molicel-inr18650-p28a-2800mah-13c-lithium-ion-battery | 2026-09-24 | VERIFIED |
| 18650 | Molicel P28A | IHC / lionbattery | 429 (incl) / 593.22 (excl, 100 in stock) | – | available | 2.8 Ah | 42.6 / 69.4 | https://indianhobbycenter.com/products/molicel-inr-18650-p28a ; https://lionbattery.in/shop/shop/lithium-cells/li-ion-cylindrical-battery-cell/molicel-2800mah-13c-lithium-ion-battery-original-inr18650-p28a/ | 2026-09-24 | VERIFIED |
| 18650 | Molicel P28A | TBW (authorised) | 305 | n/s | **Out of stock** | – | – | https://www.thebatteryworld.in/products/molicel-inr-18650-p28a-3-6v-2800mah | 2026-09-24 | VERIFIED |
| 18650 | Molicel M35A (3C) | ElectronicsComp / IHC | 449 (excl, 111 pcs) / 499 (incl) | – | in stock | 3.5 Ah 3C | 42.0 / 39.6 | https://www.electronicscomp.com/molicel-inr-18650-m35a-36v-3500mah-3c-li-ion-battery | 2026-09-24 | VERIFIED |
| 18650 | Samsung INR18650-30Q | ElectronicsComp | 699 (→824.82) | excl | 31 | **seller states COPY, "Brand Generic, China"** | – | https://www.electronicscomp.com/samsung-inr18650-30q-3000mah-5c-li-ion-battery | 2026-09-24 | VERIFIED (counterfeit disclosed) |
| 18650 | Samsung INR18650-35E | ElectronicsComp | 719 | excl | 31 | **seller states COPY, "Generic, China", 8 A max** | – | https://www.electronicscomp.com/samsung-inr18650-35e-3500mah-2c-li-ion-battery | 2026-09-24 | VERIFIED (counterfeit disclosed) |
| 18650 | Samsung 30Q / 35E, LG MJ1 | olelectronics.in | 431 / 390 / 333 | n/s | all **Out of stock** | – | – | https://olelectronics.in/product/samsung-inr18650-30q-3000mah/ | 2026-09-24 | VERIFIED |
| 18650 | LG HG2 / MJ1, Samsung 30Q / 35E | batterysource.in | "₹110" placeholder, no price on page | n/s | – | – | – | https://batterysource.in/product/lg-inr18650hg2-3-6v-3000mah-li-ion-battery/ | 2026-09-24 | UNVERIFIED (RFQ) |
| 18650 | Sony/Murata US18650 VTC6 | Robokits | 406 | excl | **Out of Stock** | 3.0 Ah, 15 A (30 A @80 °C cut-off) | – | https://robokits.co.in/batteries-chargers/skycell-li-ion-battery/3.7v-li-ion-batteries-3.2-4.2v/sony-murata-us18650-vtc6-3000mah-7c-li-ion-cell-original | 2026-09-24 | VERIFIED |
| 18650 | DMEGC INR18650-32E / 29E / 26E | ElectronicsComp | 224 / 179 / 113 | excl | 139 / – / – | energy cells | 22.3 (32E: 224×1.18=264.32 ÷ 11.84 Wh) | https://www.electronicscomp.com/dmegc-inr18650-32e-37v-3200mah-li-ion-battery | 2026-09-24 | VERIFIED |
| 18650 | "5000 mAh 18650" (Powerbee, Hongli) | Quartz ₹85 / IHC ₹159 | – | – | – | **5 Ah in an 18650 is not credible** (credible 18650s top out near 3.5–3.6 Ah) | – | https://quartzcomponents.com/products/18650-li-ion-5000mah-rechargeable-battery | 2026-09-24 | VERIFIED (**fake-capacity flag**) |
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

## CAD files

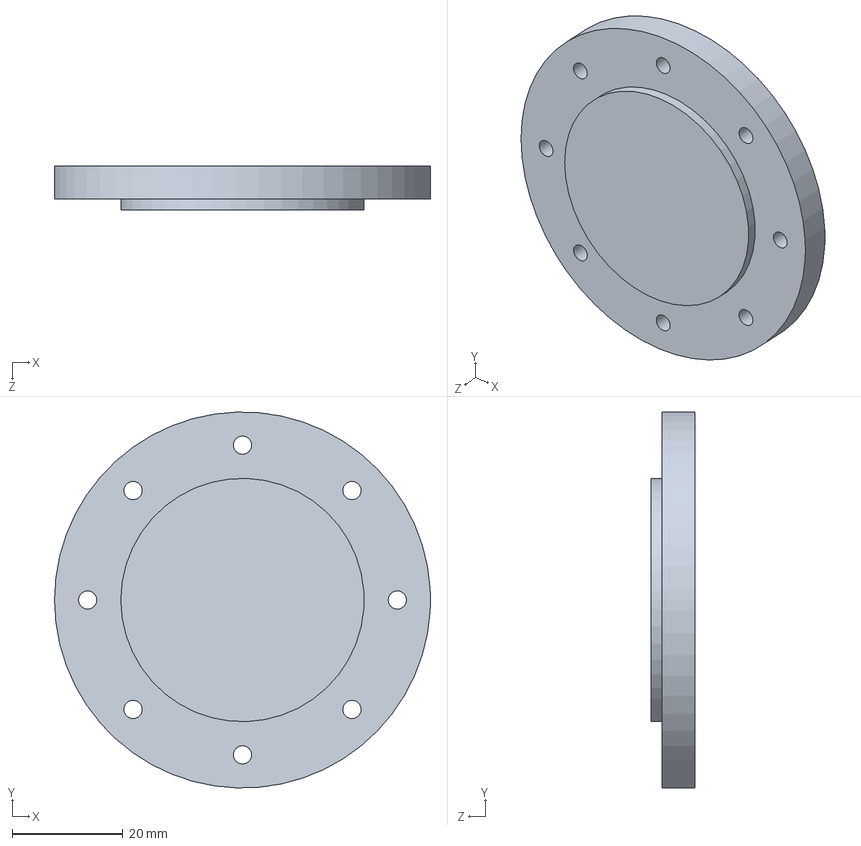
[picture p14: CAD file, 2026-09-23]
CAD/Actuators/JX1_ACT_L_Output.SLDPRT
68.0 x 68.0 x 8.00 mm

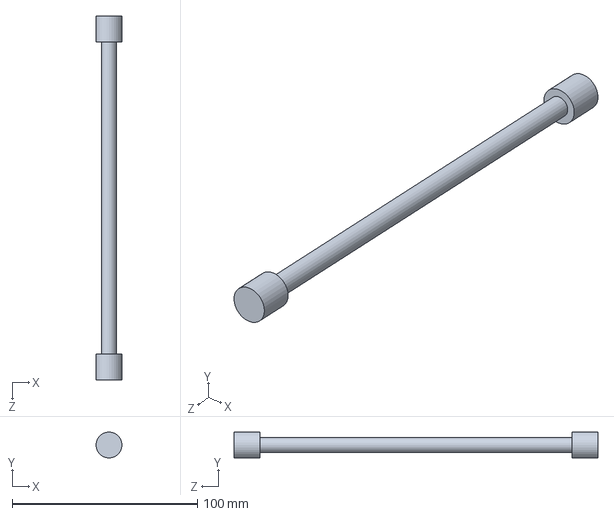
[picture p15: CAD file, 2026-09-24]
CAD/Ankle/JX1_AnkleRod_A.SLDPRT
14.0 x 14.0 x 196.7 mm

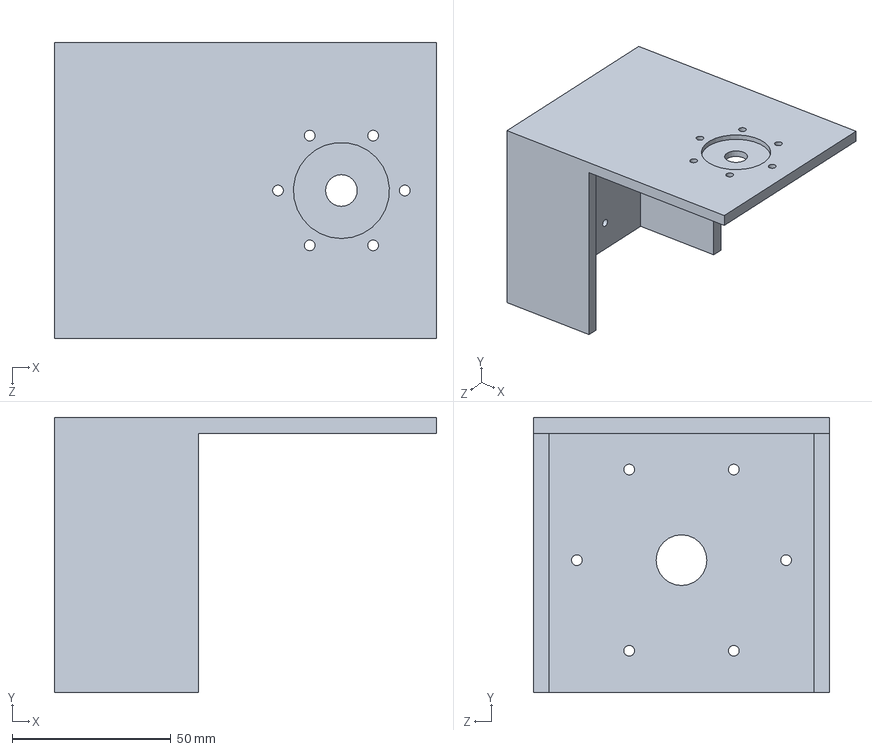
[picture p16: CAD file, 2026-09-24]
CAD/Arms/JX1_ShoulderPitchBracket_R.SLDPRT
120.5 x 86.8 x 93.5 mm

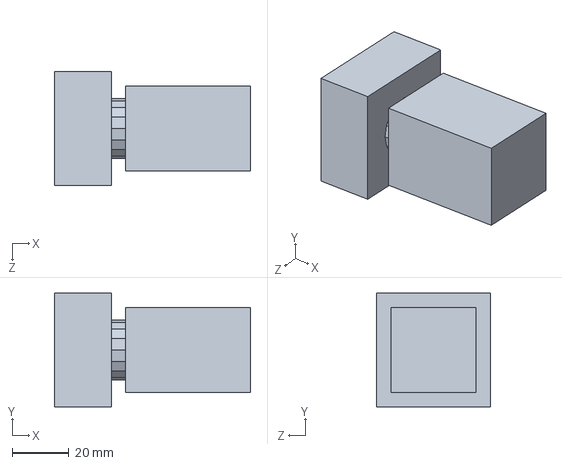
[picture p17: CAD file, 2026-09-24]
CAD/Electronics/JX1_EStop.SLDPRT
69.0 x 40.0 x 40.0 mm

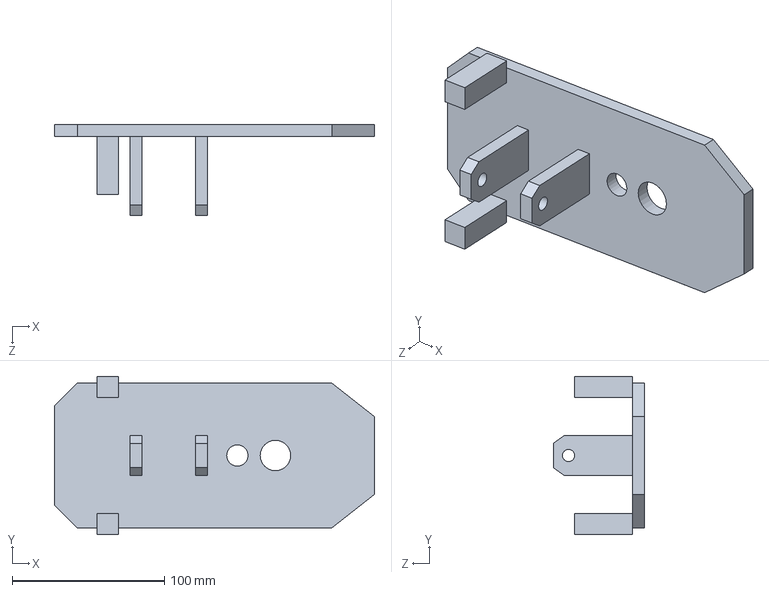
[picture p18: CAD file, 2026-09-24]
CAD/Foot/JX1_Foot_L.SLDPRT
210.0 x 104.0 x 60.0 mm

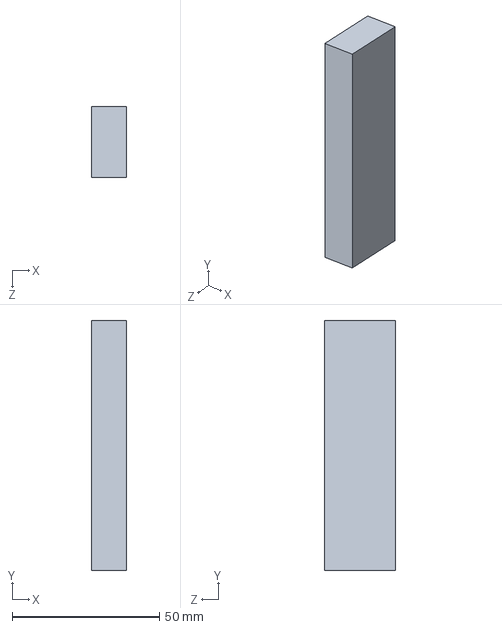
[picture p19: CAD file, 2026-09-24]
CAD/Head/JX1_StereoCamera.SLDPRT
12.0 x 85.0 x 24.0 mm

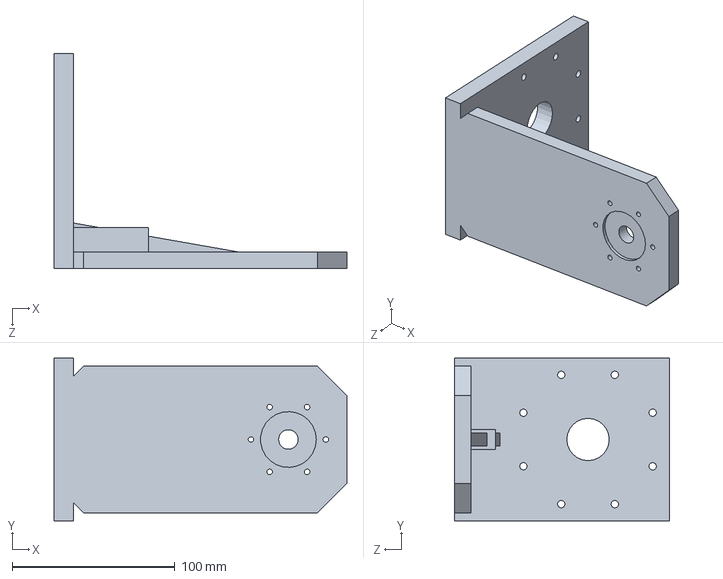
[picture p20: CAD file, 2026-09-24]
CAD/Hip/JX1_HipYawBracket_R.SLDPRT
180.0 x 100.0 x 132.0 mm

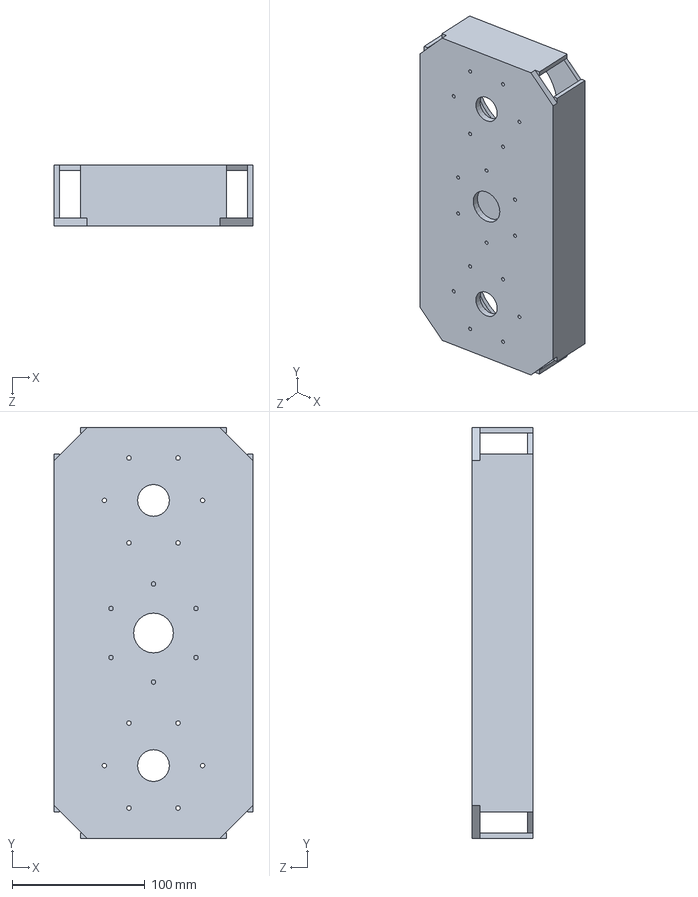
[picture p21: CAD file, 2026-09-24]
CAD/Pelvis/JX1_Pelvis.SLDPRT
150.0 x 310.0 x 46.0 mm

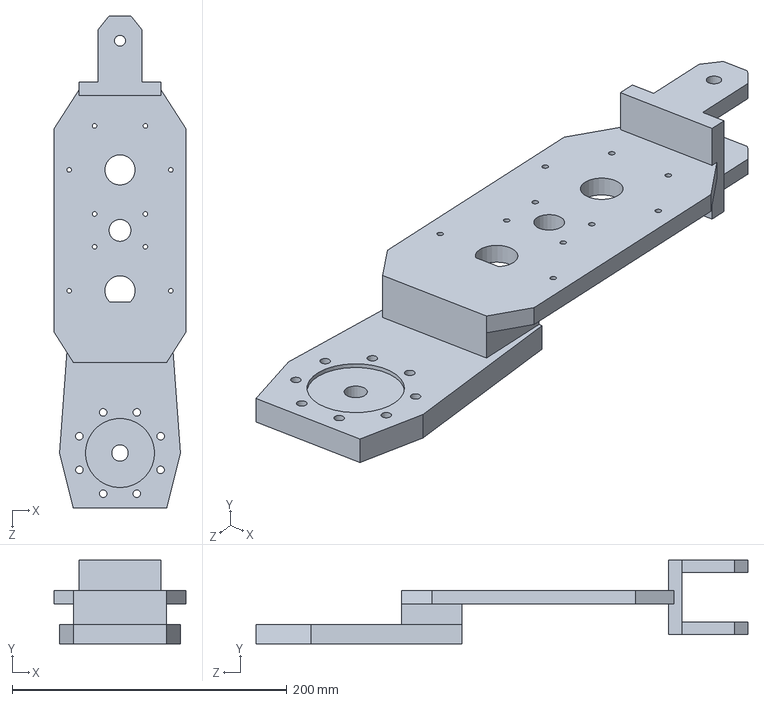
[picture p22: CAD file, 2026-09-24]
CAD/Shin/JX1_Shin_L.SLDPRT
96.0 x 61.0 x 358.0 mm

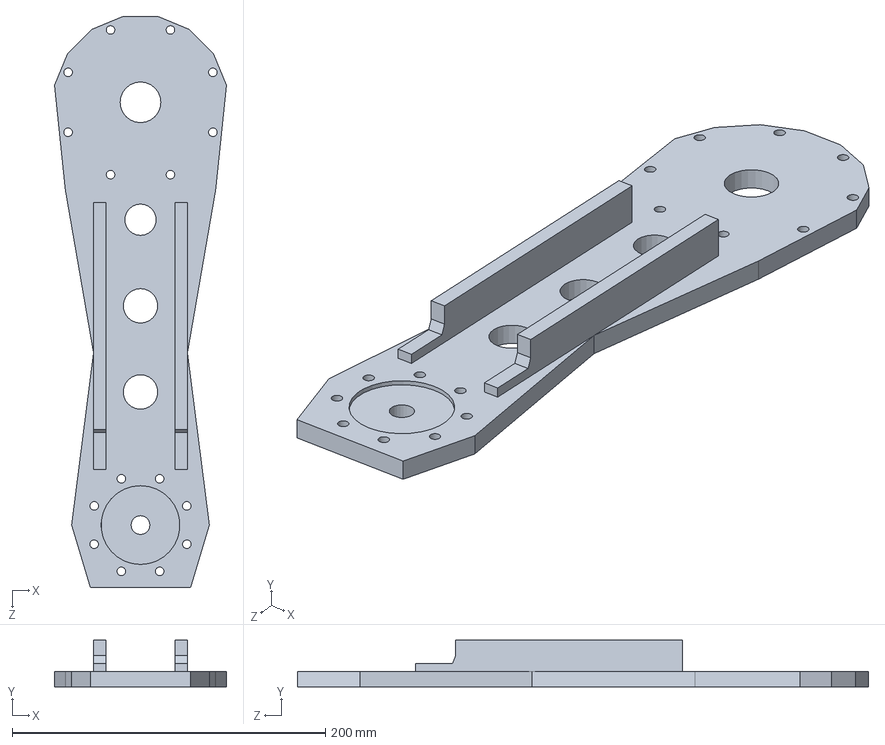
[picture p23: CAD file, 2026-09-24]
CAD/Thigh/JX1_Thigh_R.SLDPRT
109.8 x 30.0 x 364.9 mm

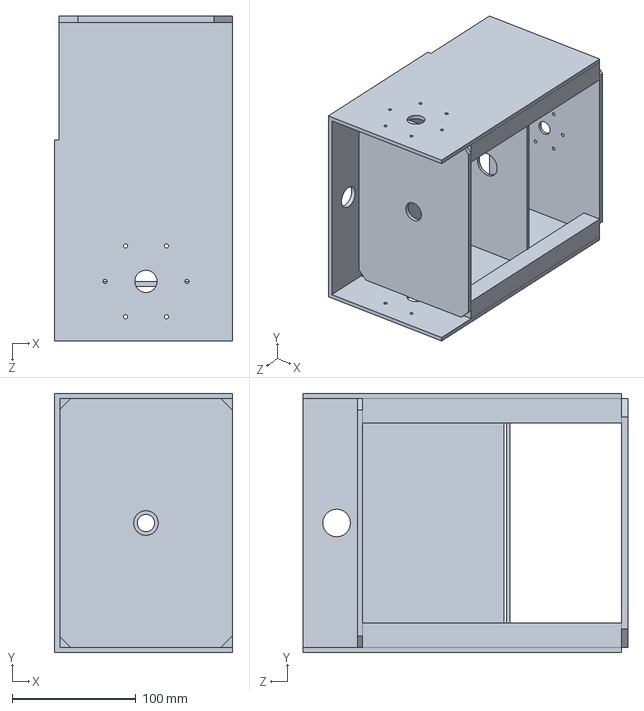
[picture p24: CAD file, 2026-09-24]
CAD/Torso/JX1_Torso.SLDPRT
144.0 x 209.0 x 262.0 mm

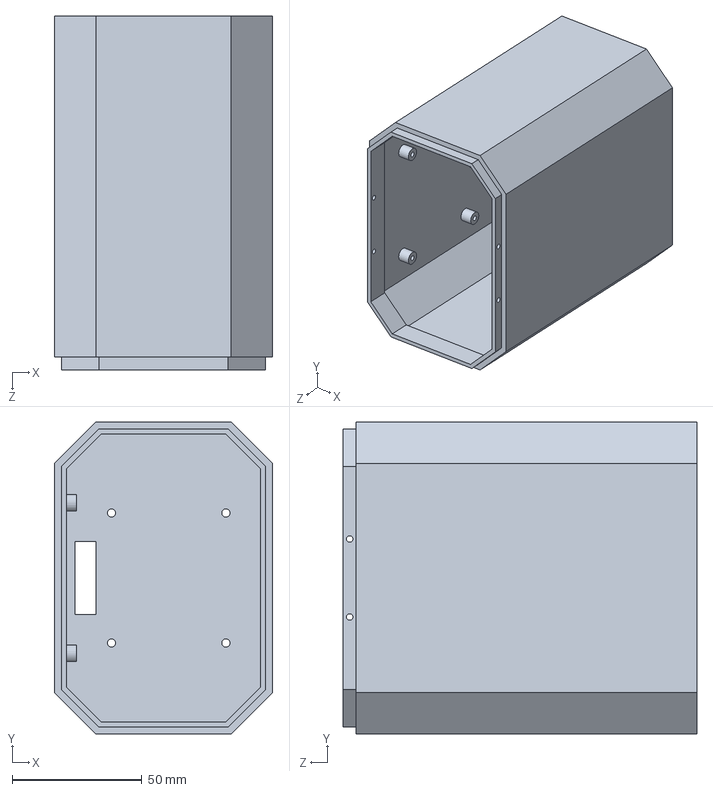
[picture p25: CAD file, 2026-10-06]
jx0/cad/parts/JX0_Torso.SLDPRT
84.0 x 120.0 x 136.0 mm

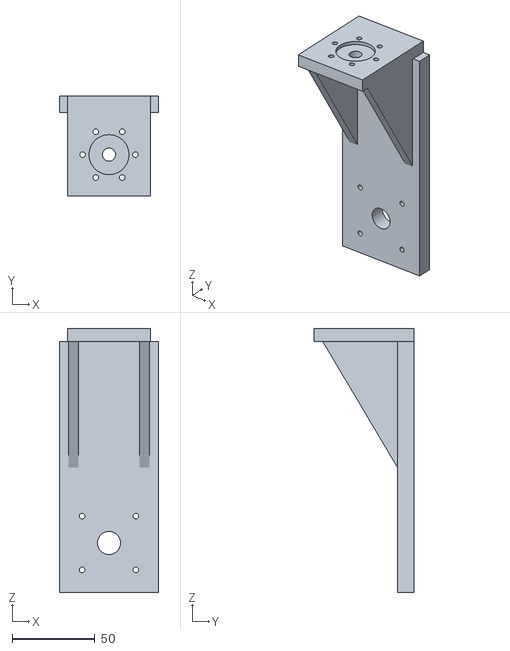
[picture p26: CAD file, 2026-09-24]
manufacturing/fit_check/JX1_UpperArm_R_FITCHECK.stl
60.0 x 60.5 x 160.0

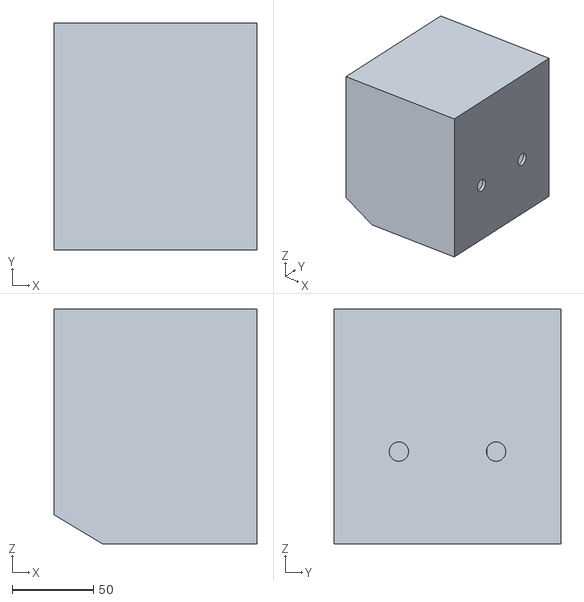
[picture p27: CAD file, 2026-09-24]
manufacturing/print/JX1_Head.stl
125.0 x 140.0 x 145.0

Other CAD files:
CAD/Assemblies/JX1_UpperBody.SLDASM
jx0/cad/JX0_Robot.SLDASM
CAD/Assemblies/JX1_Robot.SLDASM
CAD/Assemblies/JX1_LowerBody.SLDASM
CAD/Actuators/JX1_ACT_L_Housing.SLDPRT
CAD/Actuators/JX1_ACT_M_Housing.SLDPRT
CAD/Actuators/JX1_ACT_M_Output.SLDPRT
CAD/Actuators/JX1_ACT_S_Housing.SLDPRT
CAD/Actuators/JX1_ACT_S_Output.SLDPRT
CAD/Actuators/JX1_ACT_XL_Housing.SLDPRT
CAD/Actuators/JX1_ACT_XL_Output.SLDPRT
CAD/Actuators/JX1_ACT_XS_Housing.SLDPRT
CAD/Actuators/JX1_ACT_XS_Output.SLDPRT
CAD/Ankle/JX1_AnkleCrank.SLDPRT
CAD/Ankle/JX1_AnkleCross.SLDPRT
CAD/Ankle/JX1_AnkleRod_B.SLDPRT
CAD/Arms/JX1_Forearm_L.SLDPRT
CAD/Arms/JX1_Forearm_R.SLDPRT
CAD/Arms/JX1_Gripper.SLDPRT
CAD/Arms/JX1_ShoulderPitchBracket_L.SLDPRT
CAD/Arms/JX1_ShoulderRollBracket_L.SLDPRT
CAD/Arms/JX1_ShoulderRollBracket_R.SLDPRT
CAD/Arms/JX1_UpperArm_L.SLDPRT
CAD/Arms/JX1_UpperArm_R.SLDPRT
CAD/Drawings/JX1_AnkleCrank.SLDDRW
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

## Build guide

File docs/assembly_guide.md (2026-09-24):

# How to assemble JX1 — step by step (v0.5, 2026-09-24)

This guide puts the 87 parts of JX1 together in 22 steps, in the order a real build would go. Every picture is rendered
from the actual CAD parts in their verified positions (`tools/media/assembly_film.py`). The same sequence is animated in
the **[assembly film](../media/jx1_assembly.mp4)** (96 s).

> **Honest status.** Nobody has built JX1 yet. This sequence comes from the CAD, where every joint and clearance was
> checked. It has not been tried on a real bench. Two things are still open. First, the actuator bolt patterns (hole
> circle, thread, pilot) are **ASSUMED** until the official RobStride drawings or a measured unit are in the CAD (open
> issue [OI-1](open_issues.md)). Second, the bolt torques are not specified yet. Do the fit-check prints first
> ([build guide §4](build_guide.md#4-printing-notes)).

**New to this?** Read the [README](../README.md) first ("How JX1 works" and the glossary). It explains every word used
here: actuator, output flange, pilot, dowel, CAN ID, zero pose.

---

## Before you start

### Words you will see

- **Actuator**: a motor, gearbox, encoder and motor driver in one round can. JX1 uses 21 of them from RobStride in five
  sizes. Each one has a **housing** (the body, fixed) and an **output flange** (the face that turns). Parts bolt to both.
- **Pilot**: a shallow round step on the flange. The mating part has a matching recess, which centres the part so the
  bolts don't have to.
- **Dowel pin**: a hardened steel pin pressed into two plates. It stops the plates sliding past each other. Bolts clamp
  the plates; dowels locate them.
- **Left / right** always means the **robot's** left and right, as if you were standing inside it.
- **Zero pose**: legs straight, feet flat and parallel, arms hanging straight down, head looking forward. Every joint
  angle in the software is measured from this pose.

### Tools

Hex keys 2 / 2.5 / 3 / 4 mm (ball-end and straight), a torque screwdriver (0.5–5 N·m) and a small torque wrench,
medium-strength thread-locker (blue, e.g. Loctite 243), a digital caliper, taps and drills for M3/M4/M5, Ø5 and Ø8 H7
reamers, a deburring tool, a small hammer and pin punch for the dowels, a multimeter, a soldering iron, heat-shrink, an
XT30 crimp/solder kit, cable ties, and spiral wrap. For the steps after assembly you need a lifting gantry or harness
([safety architecture §6](safety_architecture.md)).

### Fasteners (from `tools/cad/params.py`; patterns ASSUMED, OI-1)

| Actuator (joints) | Size | Output flange | Housing (rear) | Bolt |
|---|---|---|---|---|
| RS04 (hip pitch, knee) | Ø120 × 50 mm, 1.42 kg | 8 holes on Ø64, pilot Ø50 | 8 holes on Ø100 | M5 |
| RS03 (hip roll) | Ø106 × 50 mm, 0.88 kg | 8 holes on Ø56, pilot Ø44 | 8 holes on Ø86 | M4 |
| RS06 (hip yaw, ankle ×2, waist) | Ø88 × 44 mm, 0.62 kg | 6 holes on Ø46, pilot Ø34 | 6 holes on Ø74 | M3 |
| RS02 (shoulder pitch, shoulder roll) | Ø78.5 × 40.5 mm, 0.41 kg | 6 holes on Ø40, pilot Ø30 | 6 holes on Ø66 | M3 |
| RS00 (shoulder yaw, elbow) | Ø57 × 46 mm, 0.31 kg | 6 holes on Ø32, pilot Ø24 | 4 holes on Ø46 | M3 |

- Use **12.9-grade socket-head cap screws** (Unbrako or equivalent, BOM JX1-020). Put blue thread-locker on every bolt
  that goes into metal. Keep it away from plastic parts: thread-locker cracks many plastics.
- Bolt length: the actuator manual gives the maximum thread depth into the flange. Never bottom out a screw in an
  actuator. Check each length against the manual before you order.
- **Bolted plate joints** (hip-roll bracket corner, shin joggle block, pelvis box): M5 12.9 bolts tightened to about
  70 % of their proof load, plus Ø5 steel dowels. On the hip-roll corner the two dowels go at the two ends of the joint,
  at least 70 mm apart. M5 threads in the 20 × 20 corner bar need at least 10 mm of engagement or a helicoil
  (open issue [OI-17](open_issues.md): design loads and hand sizing done; checking with strain gauges on the prototype
  comes next).

### Prepare every actuator first (do this on the bench, not in the robot)

1. Connect one actuator at a time to the USB-CAN adapter (Waveshare USB-CAN-A) and a current-limited bench supply.
2. **Set its CAN ID** from the table in [electrical wiring §2](electrical_wiring.md#2-can-harness-6-buses-classic-can-1-mbits-29-bit-ids).
   Left leg 11–16, left arm 21–24, waist 31, right leg 41–46, right arm 51–54. Read its feedback and fault flags.
3. **Label it**: CAN ID and joint name, on tape on the housing (for example "13 L_HIP_PITCH").
4. Check that the output turns smoothly by hand when the actuator is unpowered.

A wrong CAN ID in a finished robot means taking a leg apart. Five minutes on the bench saves an evening.

### Connector direction matters

Each actuator has one XT30 power socket and one small JST-GH CAN socket on its housing. The CAD sets which way each
connector points, and the cable routes in [electrical wiring §5](electrical_wiring.md#5-routing-through-joints) depend
on it. Before you tighten a housing, compare it with the step picture. If you mount a housing one bolt hole round, the
connector ends up where a joint can pinch the cable.

---

## Part A — Lower body (the walking part: 12 joints)

Build both legs at the same time, step by step, so they come out as exact mirrors. Right-hand parts are mirror images
of the left-hand ones. Their STEP files and drawings are separate, so don't mix them up.

### Step 1 — Pelvis torsion box

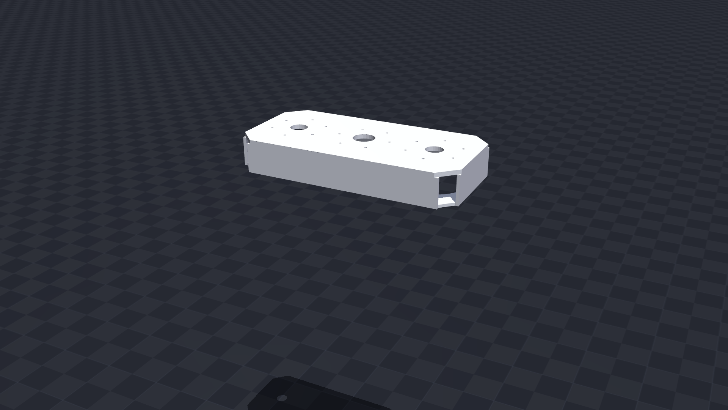
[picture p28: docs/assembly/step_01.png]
Step 1


**What it is:** the robot's hip bone. It is a closed aluminium box, and the closed box makes it very stiff in twist.
Both legs hang from it and the torso sits on top of it.

- **Parts:** pelvis top plate (6 mm), walls and bottom (4 mm), tapped 8 × 8 corner bars, all 6061-T6 (laser-cut).
- **Do:** bolt the walls to the corner bars, then fit the top and bottom plates. Check that the box is square on a flat
  surface before you do the last bolts up tight. Fit the IMU (BNO085) inside the box on the centre line, with its axes
  square to the box. The simulation model puts it 50 mm above the pelvis origin (`simulation/mujoco/jx1.xml`, site `imu`),
  and the walking policy expects its axes to line up with the pelvis.
- **Check:** the Ø24 cable holes above each hip and the Ø30 waist hole in the centre of the top plate are clean and
  deburred. The cables pass through these later.
- *FEA safety factor 2.90 static / 3.44 fatigue (needs ≥ 1.5).*

### Step 2 — Hip-yaw actuators (L 11, R 41)

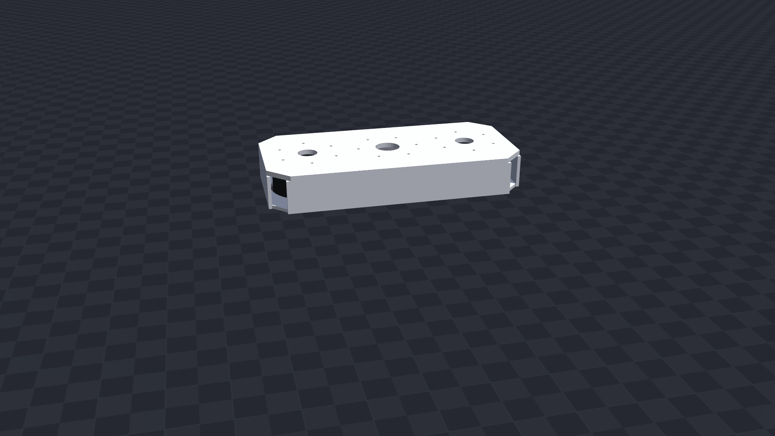
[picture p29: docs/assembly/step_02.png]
Step 2


**What they do:** turn each leg left and right about a vertical axis, for turning and toe-in/out.

- **Parts:** 2 × RobStride RS06.
- **Do:** bolt each housing under the pelvis top plate with the output flange facing **down** and the axis vertical.
  The hip centres are 0.20 m apart (100 mm either side of the middle).
- **Check:** the connector points to where the CAD shows it, so the cable can go straight up through the Ø24 hole.

### Step 3 — Hip-yaw brackets

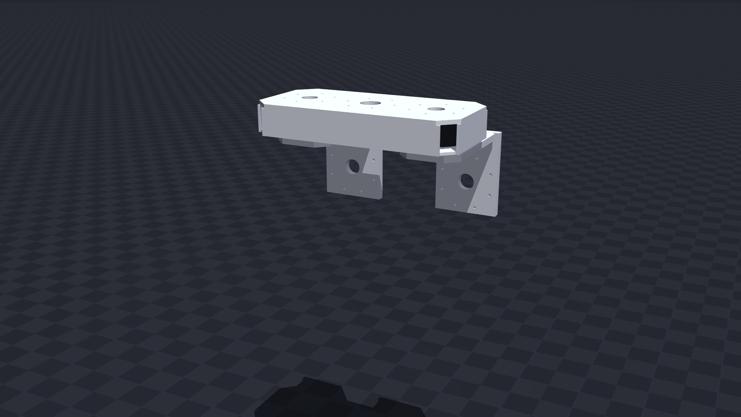
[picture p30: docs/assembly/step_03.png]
Step 3


**What they are:** the most critical parts in the robot: they have the lowest safety factor of any structural part.
Each one hangs from its hip-yaw actuator and carries the whole leg below it.

- **Parts:** 2 × hip-yaw bracket, **7075-T6** (stronger than 6061), CNC-machined from 25 mm plate. Don't substitute
  6061 here: 7075 was needed to pass the FEA.
- **Do:** seat the bracket's recess on the hip-yaw output pilot and bolt it to the output flange (6 × M3).
- **Check:** turn each bracket by hand from −40° to +45° (left) or −45° to +40° (right). Nothing touches. **Toe-out
  limit:** the two bracket tails touch if both hips toe out by about 21° each at the same time. The software keeps
  (left toe-out + right toe-out) ≤ 40° (open issue [OI-24](open_issues.md)).
- *FEA safety factor 1.77 / 1.58.*

### Step 4 — Hip-roll actuators (L 12, R 42)

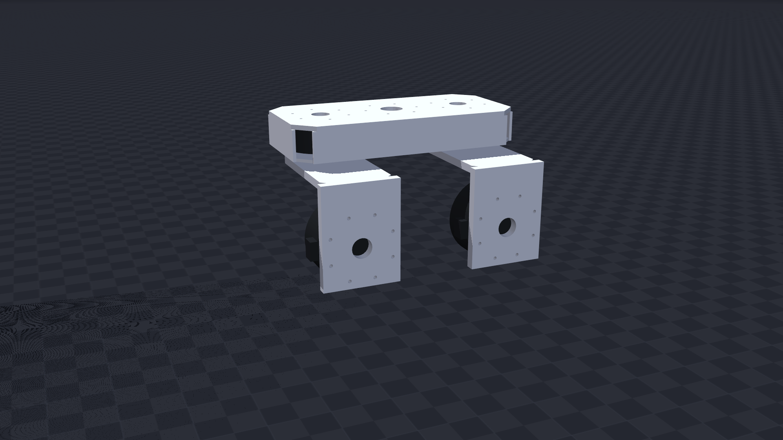
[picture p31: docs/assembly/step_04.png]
Step 4


**What they do:** swing each leg out to the side. This is how the robot shifts its weight from foot to foot.

- **Parts:** 2 × RobStride RS03 (60 N·m).
- **Do:** bolt each housing into its hip-yaw bracket with the axis pointing **forward** (8 × M4).

### Step 5 — Hip-roll brackets

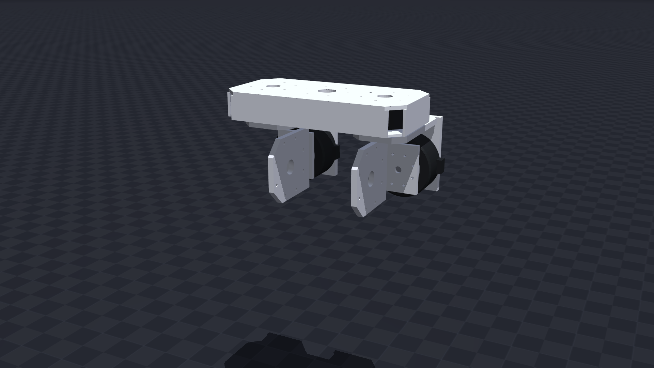
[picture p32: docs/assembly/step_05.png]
Step 5


**What they are:** L-shaped brackets that turn with hip roll and hold the hip-pitch motor.

- **Parts:** 2 × hip-roll bracket, 6061-T6 8 mm + 10 mm plates dowelled to a 20 × 20 corner bar.
- **Do:** first assemble each bracket: press the dowels in, then bolt it up (M5 12.9, see *Fasteners*). Then bolt it to
  the hip-roll output flange (8 × M4).
- **Check:** the lower edge of the back plate is 40 mm below the axis. It was shortened from 45 mm because the thigh
  touched it at full hip extension. Check the part matches the drawing.
- *FEA safety factor 2.76 / 3.80.*

### Step 6 — Hip-pitch actuators (L 13, R 43)

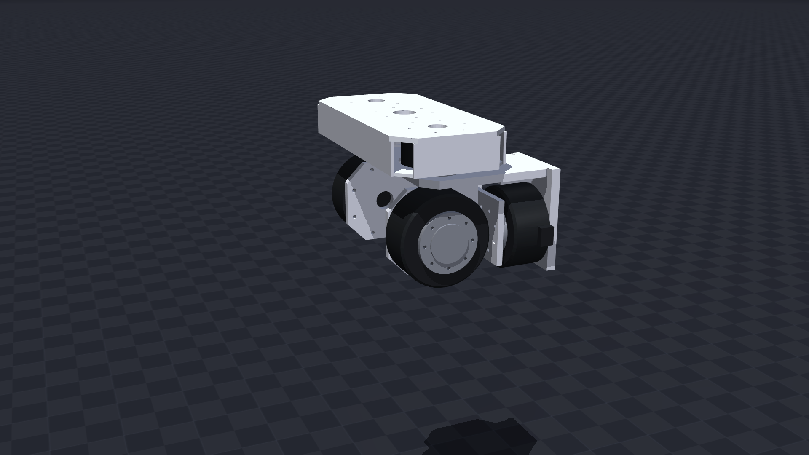
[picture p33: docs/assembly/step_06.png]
Step 6


**What they do:** swing each leg forwards and backwards. These are the walking muscles, and they are among the
strongest joints in the robot.

- **Parts:** 2 × RobStride RS04 (120 N·m).
- **Do:** bolt each housing to its hip-roll bracket with the axis pointing **sideways** (8 × M5). The three hip axes
  (yaw, roll, pitch) meet at one point. This is what makes the leg maths simple.

### Step 7 — Thighs

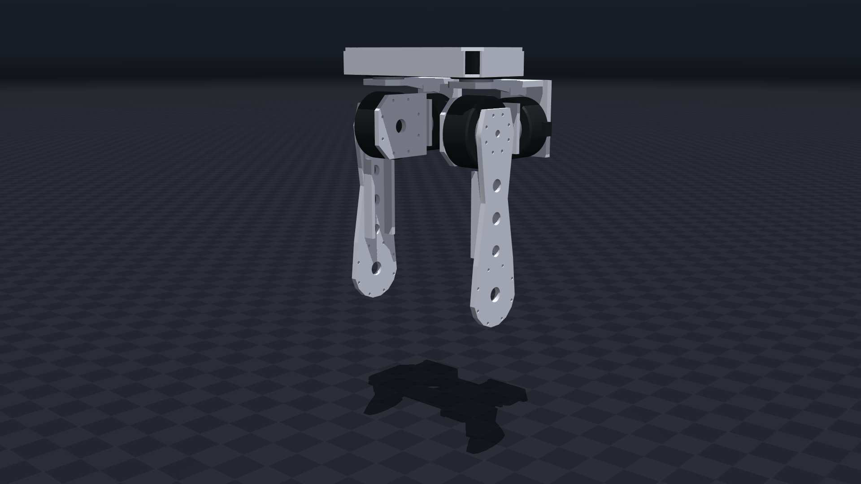
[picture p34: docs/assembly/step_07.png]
Step 7


- **Parts:** 2 × thigh, 6061-T6, 0.27 m from hip axis to knee axis. It is a 10 mm plate with run-out flanges, CNC-cut
  from 30 mm plate (or 10 mm plate with bolted flange bars).
- **Do:** bolt the thigh to the hip-pitch output flange (8 × M5, on the pilot).
- **Check:** swing the thigh through −115° (knee up in front) to +35° (leg back). The back flange clears the hip-roll
  back plate.
- *FEA safety factor 2.31 / 2.78.*

### Step 8 — Knee actuators (L 14, R 44)

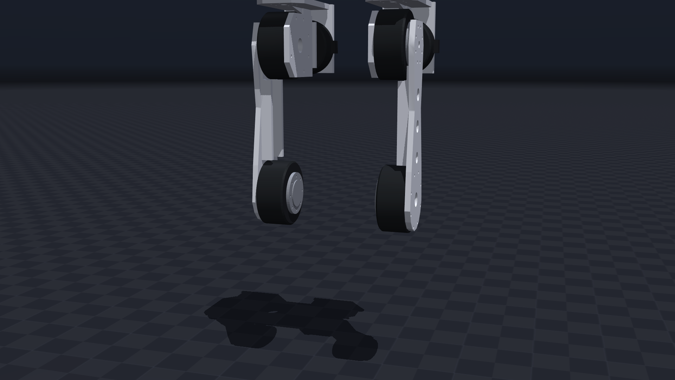
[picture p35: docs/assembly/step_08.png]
Step 8


- **Parts:** 2 × RobStride RS04 (120 N·m). The knee works hardest when the robot crouches.
- **Do:** bolt each knee housing's back face to the lower end of the thigh (8 × M5). Point the connector **backwards**:
  the cable loops behind the knee, away from the pinch zone.
- **Knee range:** 0° (straight) to 120° (bent). It never bends backwards.

### Step 9 — Shins

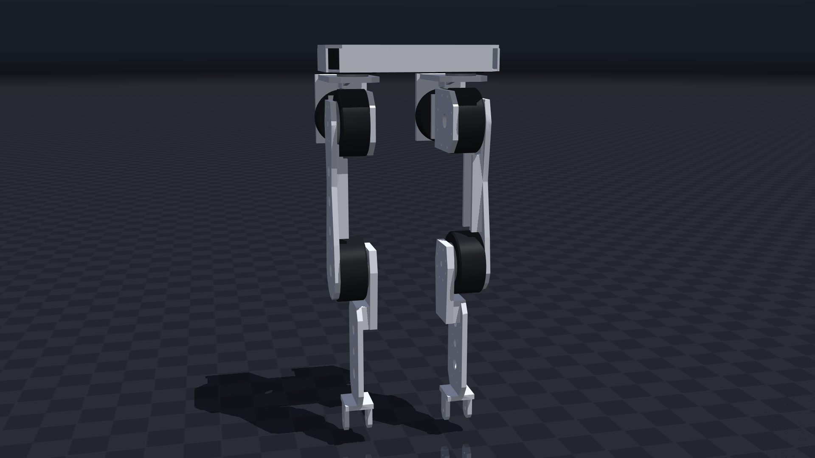
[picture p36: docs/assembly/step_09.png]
Step 9


- **Parts:** 2 × shin, 6061-T6, 0.30 m. Each has a 14 mm knee plate, a machined joggle block, a 10 mm central web and
  9 mm fork tines at the bottom.
- **Do:** assemble the shin first (knee plate, joggle block, web; 4 × M5 12.9 per interface). Then bolt it to
  the knee output flange (8 × M5).
- *FEA safety factor 3.37 / 4.17.*

### Step 10 — Ankle motors and cranks (L 15/16, R 45/46)

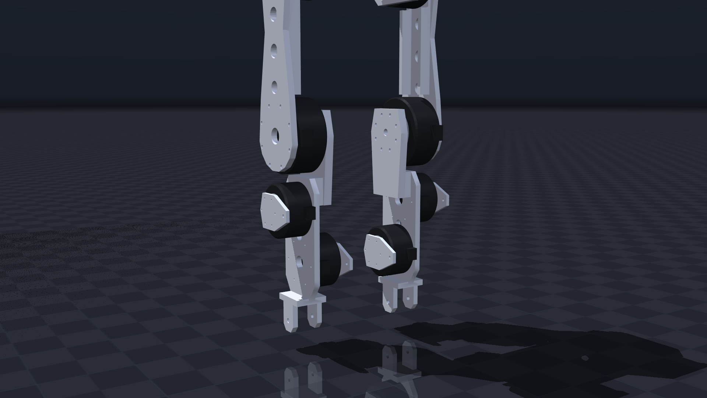
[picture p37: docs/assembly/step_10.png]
Step 10


**How the ankle works:** there is no motor at the ankle itself. **Two motors sit high on the shin**, one on each side
of the web. Each drives a 50 mm crank, and each crank pushes a rod down to the foot (Step 12). Both motors turning the
same way tip the foot up and down (pitch). Opposite ways, it tilts sideways (roll). This is a **parallel ankle**. It
keeps the heavy motors near the knee, which makes the leg light at the bottom and quicker to swing.

- **Parts:** 4 × RobStride RS06 (motor A and motor B per leg), 4 × 6 mm 6061-T6 cranks.
- **Do:** bolt motor A to one side of the shin web and motor B to the other side, back faces against the web
  (6 × M3 each). Bolt a crank onto each output flange, on its pilot. Set each crank at the angle the CAD shows at the
  zero pose.

### Step 11 — Ankle cross and feet

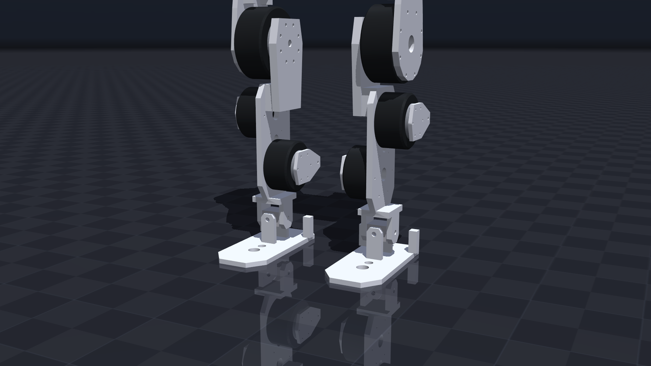
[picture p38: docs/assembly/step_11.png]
Step 11


- **Parts:** 2 × ankle cross (EN8/EN24 steel, turned and cross-drilled Ø8 H7). This is a small universal joint. Needle
  bearings go in the fork and foot bores. Also 2 × foot, 6061-T6 8 mm sole with bolted clevis tines and rod posts,
  210 × 95 mm, and 4 mm rubber sole pads.
- **Do:** press the needle bearings into their bores (see the ankle-cross and foot drawings). Fit the cross between the shin fork tines (pitch axis), then fit the foot clevis
  onto the cross (roll axis). Stick the rubber pad on the sole.
- **Check:** the foot swings freely in both directions with no play you can feel.
- *FEA safety factor 3.50 / 2.03.*

### Step 12 — Push-rods

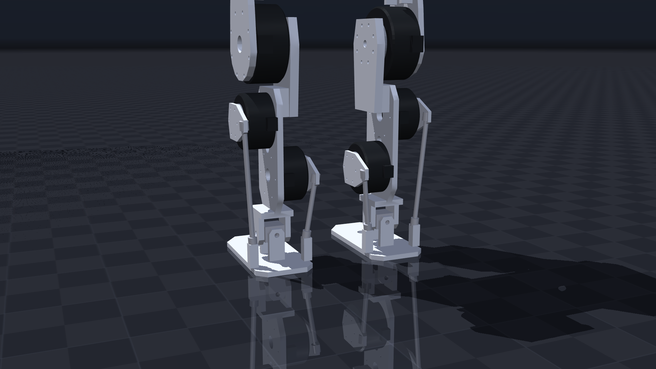
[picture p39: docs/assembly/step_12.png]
Step 12


- **Parts:** 4 push-rods (Ø8 steel, two long and two short, cut to the lengths on the push-rod drawings and tapped
  M5 at both ends), 8 × M5 rod ends (POS5/PHS5 type), lock nuts.
- **Do:** screw the rod ends in, connect each rod from its crank ball stud to its foot post, and adjust the lengths
  until the foot sits **flat and square at the zero pose** with both motors at zero. Then tighten the lock nuts.
- **Check:** by hand, the foot reaches −55° to +30° pitch and ±20° roll. The ankle corner (full toe-down plus full
  tilt) is limited in software by a *coupled limit polygon*, because one rod touches motor B's housing out there
  (open issue [OI-3](open_issues.md), resolved in the controller).

**The legs are done: 12 joints.** Now is the time to route and test the leg harness (Part E, steps 1–3). Access is
much easier before the torso is on.

---

## Part B — Torso and power

### Step 13 — Waist actuator (ID 31)

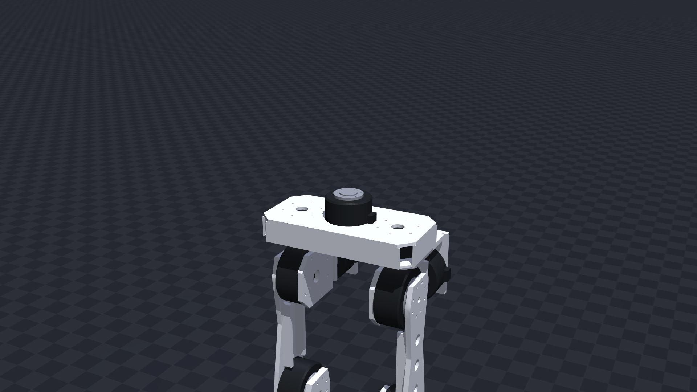
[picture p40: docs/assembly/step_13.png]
Step 13


- **Parts:** 1 × RobStride RS06. It turns the whole upper body (±90°).
- **Do:** bolt the housing on top of the pelvis, over the Ø30 centre hole, with the output facing up (6 × M3). The
  waist cable goes down through the hole with 1.5 turns of slack (a "clock-spring loop"), so the waist can turn without
  pulling on it.

### Step 14 — Torso frame

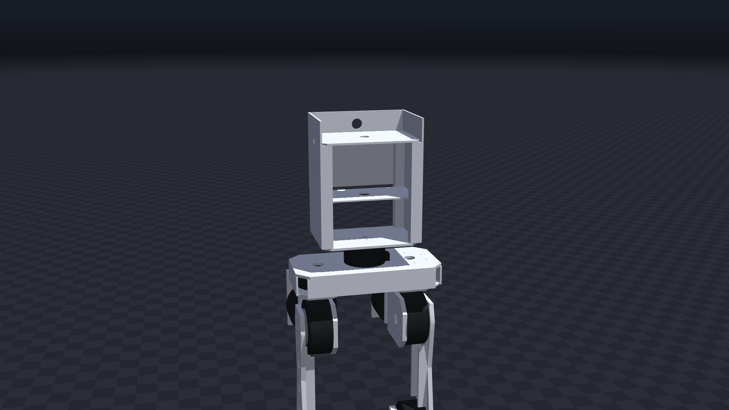
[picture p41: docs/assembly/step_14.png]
Step 14


- **Parts:** 6061-T6 plates (5 / 4 / 3 mm, laser-cut, tapped) and 4 × 2020 aluminium extrusion posts.
- **Do:** build the frame on the bench: bolt the plates to the four posts and check it is square. Then bolt the bottom
  plate to the waist output flange.
- *FEA safety factor 4.44 / 3.59.*

### Step 15 — Battery and electronics

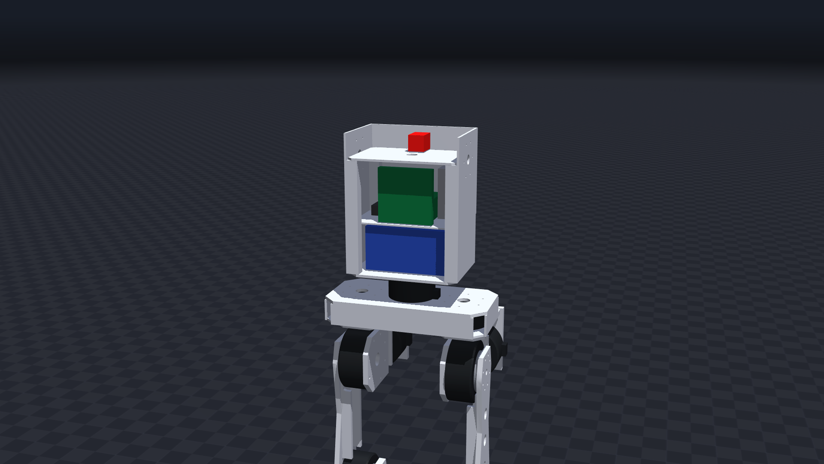
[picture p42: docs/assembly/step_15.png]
Step 15


- **Parts:** 13S2P battery pack (28 × Samsung 50S cells, 41.6–54.6 V, 468 Wh) with a JBD 40 A smart BMS, Jetson Nano
  (the "brain", runs the walking policy at 50 Hz), hub board (2 × Teensy 4.1 — they talk to all the actuators over
  6 CAN buses, 500 times a second), 5 V DC-DC supply, anti-spark power switch, and the **E-stop** button on the back.
- **Do:** follow [electrical wiring](electrical_wiring.md). Battery in its bay (low, in the middle). Jetson and hub
  board above it. E-stop where you can reach it from behind the robot.
- ⚠ **Battery safety:** a 468 Wh lithium pack can start a fire if shorted. Keep the XT90-S service disconnect out
  until the wiring is checked, and never work on live 48 V wiring.

---

## Part C — Arms (4 joints each)

### Step 16 — Shoulder-pitch actuators (L 21, R 51)

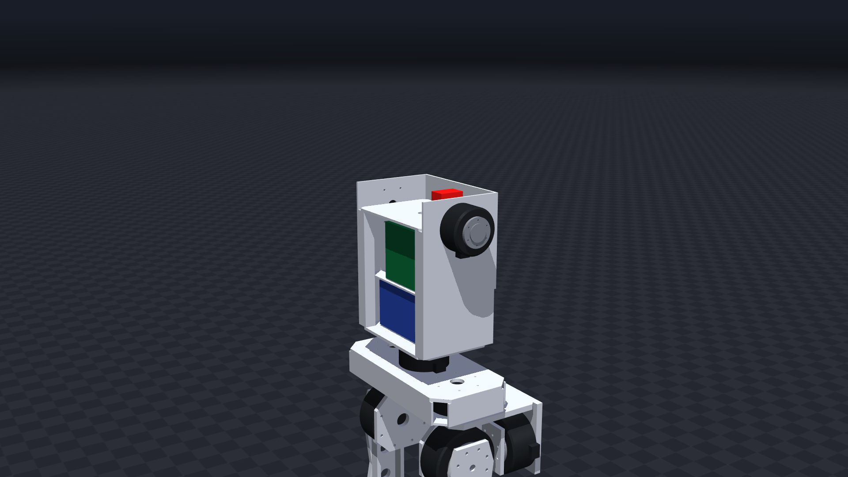
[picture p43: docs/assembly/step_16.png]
Step 16


- **Parts:** 2 × RobStride RS02 (17 N·m). They swing the arms forward and back, from −170° (overhead) to +60°.
- **Do:** bolt each housing into the side of the torso frame, axis pointing sideways (6 × M3). Point the connector as
  the CAD shows: its orientation ("clocking") was corrected during verification so the cable clears the torso.

### Step 17 — Shoulder brackets and roll actuators (L 22, R 52)

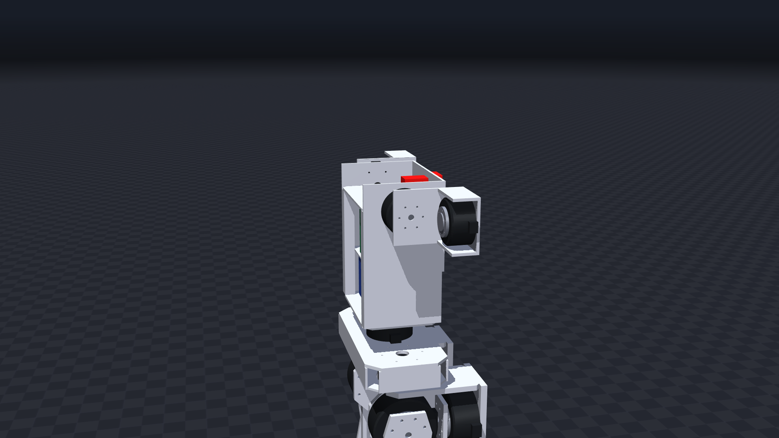
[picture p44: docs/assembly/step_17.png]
Step 17


- **Parts:** 2 × shoulder-pitch U-bracket (6061-T6, 5 mm), 2 × RobStride RS02 (shoulder roll: lifts the arm out to
  the side, −10° to +150°).
- **Do:** bolt the U-bracket to the shoulder-pitch output flange, then bolt the roll actuator into the bracket with its
  axis pointing forward.

### Step 18 — Shoulder-yaw actuators (L 23, R 53)

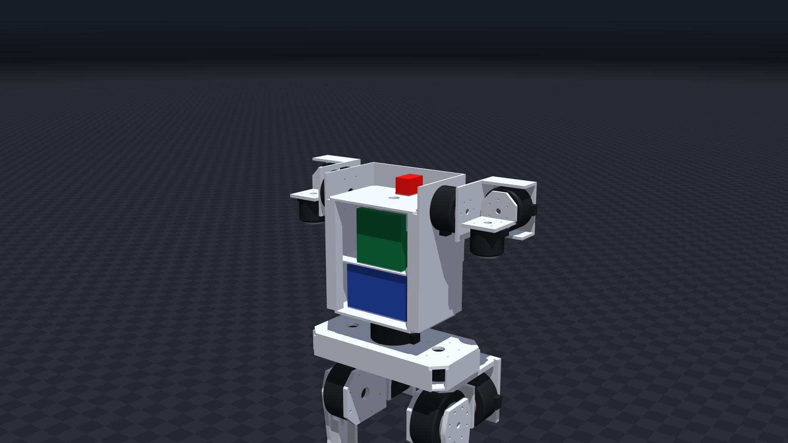
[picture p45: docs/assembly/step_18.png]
Step 18


- **Parts:** 2 × shoulder-roll L-bracket (6061-T6, 6 mm), 2 × RobStride RS00 (14 N·m; twists the arm about its own
  length, ±90°).
- **Do:** L-bracket onto the roll output flange, then the yaw actuator into the L-bracket, axis pointing down the arm.

### Step 19 — Upper arms and elbows (L 24, R 54)

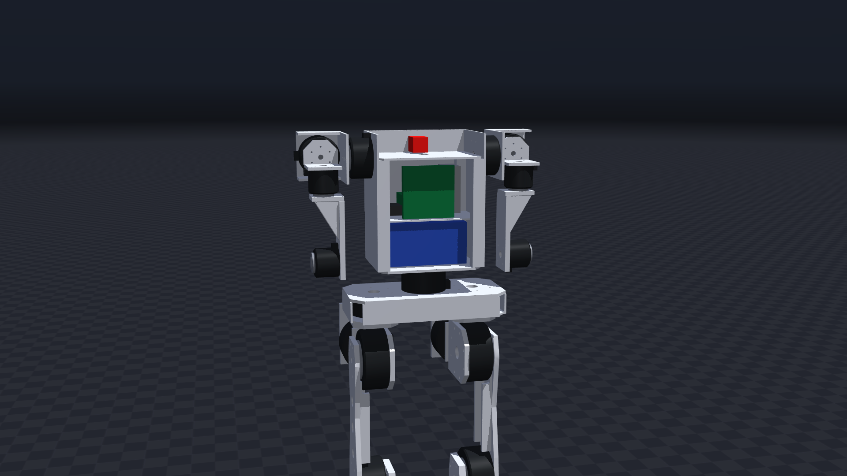
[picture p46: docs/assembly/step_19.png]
Step 19


- **Parts:** 2 × upper arm (6061-T6 10 mm + 8 mm plates with two 6 mm gussets, bolted or TIG-welded) and 2 × RobStride
  RS00 elbow (−135° to +5°).
- **Do:** bolt the upper arm to the shoulder-yaw output flange. Then bolt the elbow housing to its lower end.
- *The first 6 mm upper-arm design failed the FEA (1.34 / 1.08). This one passes easily (5.99 / 4.84). Don't thin it
  down.*

### Step 20 — Forearms and grippers

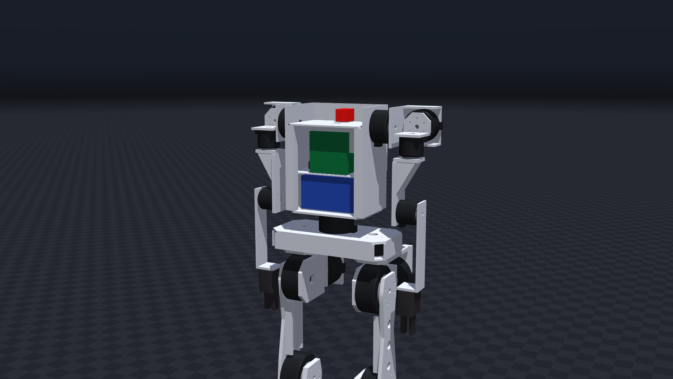
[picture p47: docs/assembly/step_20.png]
Step 20


- **Parts:** 2 × forearm (6061-T6 6 mm plates, bolted), 2 × gripper (3D-printed PA-CF body with TPU pads). The gripper
  servo is deferred to a later phase.
- **Do:** bolt the forearm to the elbow output flange and the gripper to the end of the forearm.
- **Check:** move each arm through its range by hand. With the arm raised overhead, the hand must not go behind the
  head: the software limits that combination (open issue [OI-16](open_issues.md), checked in MuJoCo on the CAD shapes).

---

## Part D — Head

### Step 21 — Neck

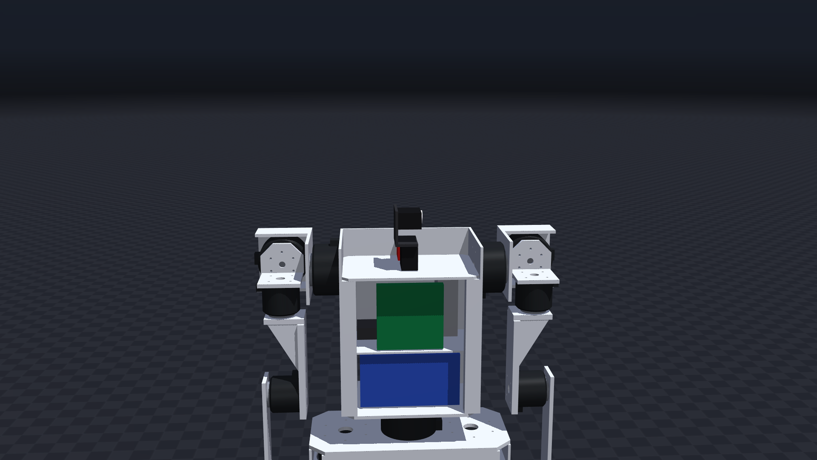
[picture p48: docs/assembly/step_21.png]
Step 21


- **Parts:** 2 × Waveshare ST3215 serial bus servos (yaw, then pitch), horns, and the neck bracket (3D-printed PA-CF,
  solid).
- **Do:** yaw servo onto the torso top deck, bracket onto the yaw horn, pitch servo into the bracket. The 3-wire servo
  cable (7.4 V + data) goes through the Ø20 hole in the deck.

### Step 22 — Head and stereo camera

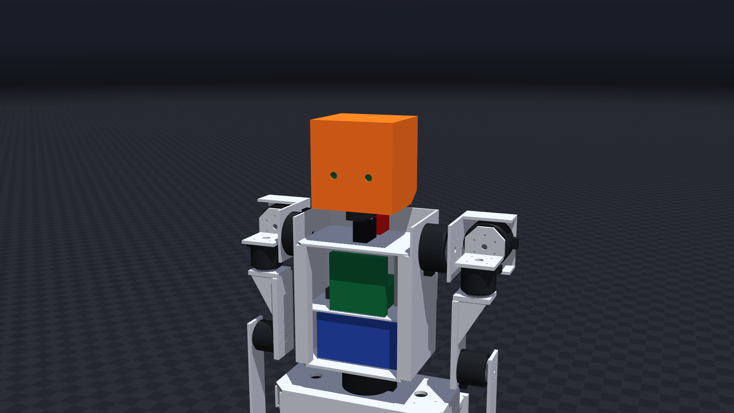
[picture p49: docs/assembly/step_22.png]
Step 22


- **Parts:** head shell (3D-printed PETG-CF, 3 walls, 25 % gyroid, about 12 h on a Bambu P1S) and a Waveshare IMX219-83
  stereo camera (the robot's eyes, 2 × 8 MP).
- **Do:** camera into the front of the shell, CSI ribbon cable down to the Jetson. Then bolt the shell onto the pitch
  servo horn.

**JX1 is assembled: 87 parts, 23 joints, 1.23 m, 33.6 kg.**

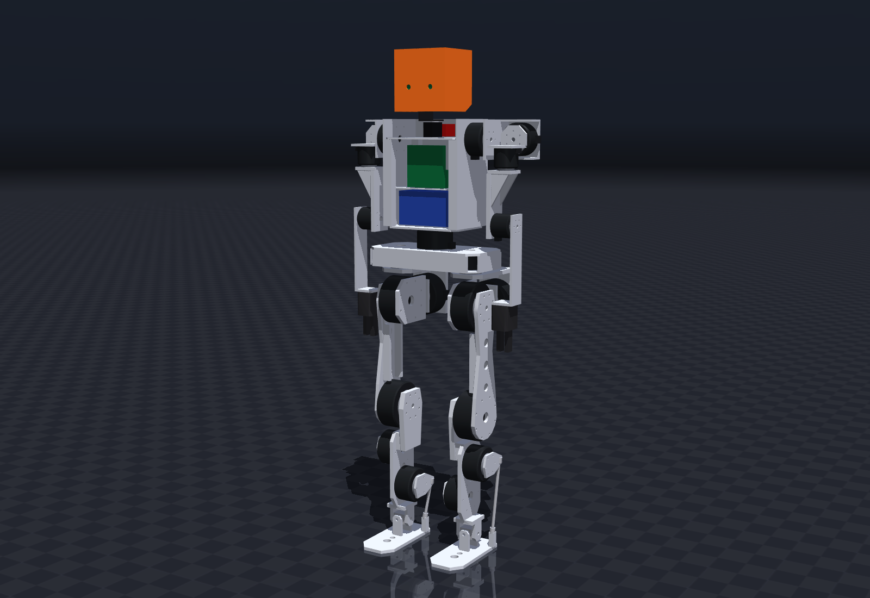
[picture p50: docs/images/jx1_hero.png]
JX1 assembled


---

## Part E — After the assembly: first power-on (the safe order)

Do these in order. Don't skip ahead. Details: [electrical wiring §6](electrical_wiring.md#6-bring-up-checklist-electrical)
and [safety architecture](safety_architecture.md).

1. **Harness check without power:** check every power trunk for continuity and for shorts to the frame. Fit the 58 V
   fuses. (32 V car fuses are **not** safe on this bus.) Across CAN-H/CAN-L you should measure 60 Ω with the power off.
   That means both 120 Ω terminators are in place.
2. **First power through a current-limited supply,** not the battery. Watch the current as you connect each actuator.
3. **E-stop test:** press it. The motor power must drop, and both hubs must report `estop` and switch every joint to
   damping. Test this **before** a leg ever moves under power.
4. **Robot on a gantry or harness with its feet off the ground.** Move one joint at a time, at low gains. Record the
   zero offsets at the zero pose. Check every joint limit against `simulation/joint_map.yaml` and every motor direction
   against the firmware config (`firmware/hub/jx1_hub/config_hub_{a,b}.h`, generated from the CAD).
5. **Feet down, still on the harness:** damping mode → PD stand → weight shifts → slow walking. Use the learned
   policy (`rl/policies/jx1_walk_stand_v7`, the default) through `ros2 launch jx1_hw hardware.launch.py`. It was checked end-to-end
   against an emulated hub first ([rl/README.md](../rl/README.md)).

If anything is unclear or doesn't fit, it goes into [open issues](open_issues.md). That list is how this design gets
better.

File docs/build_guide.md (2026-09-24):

# JX1 build guide — what to buy, machine and print, and in what order (v0.4, 2026-09-24)

Nothing has been built yet. This guide turns the verified design into a build sequence. The mechanical assembly itself
(22 steps with pictures) is in the **[assembly guide](assembly_guide.md)**; the animated version is
[media/jx1_assembly.mp4](../media/jx1_assembly.mp4). Labels as everywhere in the repo:
VERIFIED / MEASURED / CALCULATED / ESTIMATED / ASSUMED / UNVERIFIED.

## 1. The short version

- **Do not 3D-print the leg or pelvis structure** — not in PETG, not in PA-CF. The printed versions failed the strength
  analysis by a wide margin (table below); the load path is aluminium and steel.
- **Do print** full-size PETG *fit-check* copies of the metal parts first, bolt them to the real actuators, and only then
  order metal. The actuator bolt circles and pilots in the CAD are still ASSUMED (open issue OI-1).
- **Print for real** only the lightly loaded parts: head shell, covers, battery box (PETG-CF); neck bracket, gripper
  (PA-CF, TPU pads).
- The torso and arms are 6061 plate too: the FEA checked every upper-body part both ways — aluminium passes, every PA-CF
  print variant fails (SF 0.12–0.70). The upper arm was thickened after its first check (10/8 mm plates + gussets).

## 2. Why the legs cannot be printed (CALCULATED, `calculations/results/structural/`)

Voxel FEA validated against closed-form cases, loads = every actuator at its peak torque during a 3 BW landing (static)
and fast-walk loads for 1e7 cycles (fatigue); arm parts: actuator-capped shoulder/elbow moments + 75 N (3 g on arm and
1 kg payload). Required safety factor: 2.0 printed, 1.5 aluminium. Printed values: variant studies on the first-iteration
leg geometry, and the final CAD geometry evaluated as PA-CF (upper body; range over print orientations).

| Part | Printed PA-CF (static / fatigue) | Aluminium, final CAD (static / fatigue) |
|---|---|---|
| Hip-yaw bracket | 0.08 / 0.07 | 7075-T6: 1.77 / 1.58 |
| Hip-roll bracket | 0.35 / 0.37 | 6061-T6: 2.76 / 3.80 |
| Thigh | — | 6061-T6: 2.31 / 2.78 |
| Shin | 0.35 / 0.43 | 6061-T6: 3.37 / 4.17 |
| Foot | 0.74 / 0.33 | 6061-T6: 3.50 / 2.03 (lightening hole moved off the clevis; 1.48 fatigue before) |
| Pelvis | 0.90 / 0.73 | 6061-T6: 2.90 / 3.44 |
| Torso frame | 0.70 / 0.42 | 6061-T6: 4.44 / 3.59 |
| Shoulder-pitch bracket | 0.24–0.41 / 0.15–0.25 | 6061-T6: 2.17 / 1.75 |
| Shoulder-roll bracket | 0.23–0.36 / 0.14–0.21 | 6061-T6: 2.05 / 1.66 |
| Upper arm | 0.73–1.23 / 0.44–0.74 | 6061-T6, 10/8 mm + gussets: 5.99 / 4.84 (6 mm version failed: 1.34 / 1.08) |
| Forearm | 0.36–0.56 / 0.21–0.34 | 6061-T6: 3.27 / 2.65 |

PA-CF (eSUN ePA-CF, 84 MPa in-layer, 6.5 GPa) is stronger and stiffer than PETG, so PETG parts would be worse still; PETG
also creeps under the constant load of a standing robot.

## 3. What each part is made from

| Part | Qty | Material | Process | Files |
|---|---|---|---|---|
| Hip-yaw bracket L/R | 1 + 1 | 7075-T6 | CNC 3-axis from 25 mm plate | `manufacturing/step`, drawing (PDF) |
| Hip-roll bracket L/R | 1 + 1 | 6061-T6 | laser/waterjet 8 + 10 mm plates, drilled/tapped, dowelled to a 20×20 corner bar | STEP, PDF |
| Thigh L/R | 1 + 1 | 6061-T6 | CNC, 2 setups from 30 mm plate (or 10 mm plate + bolted flange bars) | STEP, PDF |
| Shin L/R | 1 + 1 | 6061-T6 | laser 10/14 mm plates + CNC joggle block + 9 mm fork tines, bolted/dowelled | STEP, PDF |
| Foot L/R | 1 + 1 | 6061-T6 | laser 8 mm sole + bolted clevis tines and posts; 4 mm rubber sole pad | STEP, PDF |
| Pelvis box | 1 | 6061-T6 | laser 6/4 mm plates + tapped 8×8 corner bars | STEP, PDF |
| Ankle crank | 4 | 6061-T6 | laser/CNC 6 mm plate, pilot recess | STEP, PDF |
| Ankle cross | 2 | EN8/EN24 steel | turned, cross-drilled Ø8 H7 | STEP, PDF |
| Ankle push-rods A/B | 2 + 2 | Ø8 steel rod | cut to length, M5×12 tapped both ends, IKO PHS5 rod ends | STEP, PDF |
| Torso frame | 1 | 6061-T6 + 4× 2020 extrusion | laser 5/4/3 mm plates, tapped, bolted to the posts | STEP, PDF |
| Shoulder-pitch U-bracket L/R, shoulder-roll L-bracket L/R | 1 + 1 each | 6061-T6 | laser 5 / 6 mm plates, bolted | STEP, PDF |
| Upper arm L/R | 1 + 1 | 6061-T6 | laser 10 + 8 mm plates + 2× 6 mm gussets, bolted or TIG-welded | STEP, PDF |
| Forearm L/R | 1 + 1 | 6061-T6 | laser 6 mm plates, bolted | STEP, PDF |
| Head shell | 1 | PETG-CF | FDM, 3 walls, 25 % gyroid | `manufacturing/print` |
| Neck bracket | 1 | PA-CF | FDM, solid | `manufacturing/print` |
| Gripper | 2 | PA-CF body + TPU pads | FDM | `manufacturing/print` |
| Covers, battery box | — | PETG-CF | FDM (phase 3) | — |

`manufacturing/index.md` (generated by `tools/cad/make_manufacturing.py`) lists every file. Right-hand parts are mirrors;
their STEP files are exported separately. The STEP file is the dimensional master; each A3 PDF carries the views,
material, process, quantity, general tolerance (ISO 2768-m), envelope, SolidWorks mass and every hole/bore by diameter,
plus the note that actuator bolt patterns must be confirmed before release. H7 on pin bores. The drawings come from a
SolidWorks Educational licence and carry its "For Instructional Use Only" stamp (see open issue OI-19).

## 4. Printing notes

- **Fit-check copies (PETG, `manufacturing/fit_check/*_FITCHECK.stl`)**: plain PETG, 0.2 mm layers, 3 walls, 15 % infill.
  Use them to check hole positions, pilots, clearances, rod-end travel and cable routes on the real actuators with the leg
  off the ground. Never load them. FDM holes print slightly undersize — drill them to size for the check.
- **PA-CF parts**: dry the filament before printing, use a hardened nozzle, print load-bearing plates up to 10 mm fully
  solid (≥ 6 perimeters), 100 % infill within 8 mm of every bolt hole, metal washers ≥ 2.5 d under bolt heads
  (`calculations/structural/materials.yaml`).

## 5. Buying (prices from `bom/master_bom.csv`, INR incl. GST/duty where stated)

- Actuators are 77 % of the robot (₹5,45,998). Phase 1 (legs) needs 12: 4× RS04 (hip pitch, knee), 2× RS03 (hip roll),
  6× RS06 (hip yaw, ankle motors) = ₹3,70,788. Phase 2 adds RS06 (waist), 4× RS02, 4× RS00 = ₹1,75,210.
  The same units through a China distributor would save ≈ ₹1,87,074 (see `bom/cost_summary.md`).
- Metal leg + pelvis set: ≈ ₹42,600 ESTIMATED from job-shop hourly rates — get real quotes (OI-12) with the STEP + PDF set
  (Robocon CNC, Makenica, or a local laser/CNC shop).
- Bench items first: Waveshare USB-CAN-A adapter (₹2,189), a current-limited bench supply, one actuator of each class.

## 6. Build order

1. **Lock the actuator interfaces (OI-1).** Get the official RobStride STEP files (or measure one unit of each class),
   put the bolt-circle diameters, thread sizes and pilot diameters into `tools/cad/params.py`, and rebuild the CAD
   (README → *Reproduce*). The CAD is parametric: a rebuild, not a redraw. Re-run the verification and FEA.
2. **Bench electronics** (`docs/electrical_wiring.md` §6): one actuator on the USB-CAN adapter — set its CAN ID, read
   feedback and fault flags; then the Teensy hub firmware (`firmware/hub/jx1_hub`) with one bus populated; E-stop test.
3. **Fit-check prints** on the real actuators (section 4). Fix anything found, rebuild, re-export.
4. **Order metal** with the updated STEP/PDF set; order the phase-1 actuators.
5. **One leg on a clamp stand**: single-joint tests at low gains, set zero offsets, check every joint limit against
   `simulation/joint_map.yaml` and every motor sign against the firmware config (`config_hub_a.h` / `config_hub_b.h`,
   derived from the CAD).
6. **Both legs + pelvis on a lifting gantry with a chest harness** (`docs/safety_architecture.md` §6): damping mode →
   PD stand (gains from `tools/sim/build_robot_description.py`, KP/KD tables) → weight shifts → slow walking with the
   gait validated in MuJoCo (`simulation/mujoco/walk_jx1.py`).
7. **Phase 2 upper body**: torso frame, battery, Jetson and hub board, arms (all 6061 plate), head and camera
   ([assembly guide](assembly_guide.md) steps 13–22).

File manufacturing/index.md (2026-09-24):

# JX1 manufacturing package (v0.4)

Generated by `tools/cad/make_manufacturing.py` from the native SolidWorks parts.
STEP files are the quote/CAM source; PDFs are A3 third-angle drawings with dimensions imported from the parametric
sketches (verify before release). **Actuator bolt patterns are ASSUMED until the RobStride STEP files are dimensioned (OI-1).**

| Part | Material | Process | Qty/robot | STEP / STL | Drawing |
|---|---|---|---|---|---|
| JX1_HipYawBracket_L | 7075-T6 | CNC 3-axis from 25 mm plate | 1 | [JX1_HipYawBracket_L.STEP](../manufacturing/step/JX1_HipYawBracket_L.STEP) | [pdf](../manufacturing/drawings/JX1_HipYawBracket_L.pdf) |
| JX1_HipYawBracket_R | 7075-T6 | CNC 3-axis from 25 mm plate (mirror of L) | 1 | [JX1_HipYawBracket_R.STEP](../manufacturing/step/JX1_HipYawBracket_R.STEP) | - |
| JX1_HipRollBracket_L | 6061-T6 | laser/waterjet 8 + 10 mm plates, drill/tap, dowel to 20x20 corner bar | 1 | [JX1_HipRollBracket_L.STEP](../manufacturing/step/JX1_HipRollBracket_L.STEP) | [pdf](../manufacturing/drawings/JX1_HipRollBracket_L.pdf) |
| JX1_HipRollBracket_R | 6061-T6 | as L, mirrored | 1 | [JX1_HipRollBracket_R.STEP](../manufacturing/step/JX1_HipRollBracket_R.STEP) | - |
| JX1_Thigh_L | 6061-T6 | CNC 2 setups from 30 mm plate (or 10 mm plate + bolted flange bars) | 1 | [JX1_Thigh_L.STEP](../manufacturing/step/JX1_Thigh_L.STEP) | [pdf](../manufacturing/drawings/JX1_Thigh_L.pdf) |
| JX1_Thigh_R | 6061-T6 | as L, mirrored | 1 | [JX1_Thigh_R.STEP](../manufacturing/step/JX1_Thigh_R.STEP) | - |
| JX1_Shin_L | 6061-T6 | laser 10/14 mm plates + CNC joggle block + 9 mm fork tines, bolted/dowelled | 1 | [JX1_Shin_L.STEP](../manufacturing/step/JX1_Shin_L.STEP) | [pdf](../manufacturing/drawings/JX1_Shin_L.pdf) |
| JX1_Shin_R | 6061-T6 | as L, mirrored | 1 | [JX1_Shin_R.STEP](../manufacturing/step/JX1_Shin_R.STEP) | - |
| JX1_Foot_L | 6061-T6 | laser 8 mm sole + bolted clevis tines and posts | 1 | [JX1_Foot_L.STEP](../manufacturing/step/JX1_Foot_L.STEP) | [pdf](../manufacturing/drawings/JX1_Foot_L.pdf) |
| JX1_Foot_R | 6061-T6 | as L, mirrored | 1 | [JX1_Foot_R.STEP](../manufacturing/step/JX1_Foot_R.STEP) | - |
| JX1_Pelvis | 6061-T6 | laser 6/4 mm plates + tapped 8x8 corner bars | 1 | [JX1_Pelvis.STEP](../manufacturing/step/JX1_Pelvis.STEP) | [pdf](../manufacturing/drawings/JX1_Pelvis.pdf) |
| JX1_AnkleCrank | 6061-T6 | laser/CNC 6 mm plate, pilot recess | 4 | [JX1_AnkleCrank.STEP](../manufacturing/step/JX1_AnkleCrank.STEP) | [pdf](../manufacturing/drawings/JX1_AnkleCrank.pdf) |
| JX1_AnkleCross | EN8/EN24 | turn + cross-drill Ø8 H7 bores | 2 | [JX1_AnkleCross.STEP](../manufacturing/step/JX1_AnkleCross.STEP) | [pdf](../manufacturing/drawings/JX1_AnkleCross.pdf) |
| JX1_AnkleRod_A | chrome-plated steel | cut Ø8 rod to length, tap M5x12 both ends | 2 | [JX1_AnkleRod_A.STEP](../manufacturing/step/JX1_AnkleRod_A.STEP) | [pdf](../manufacturing/drawings/JX1_AnkleRod_A.pdf) |
| JX1_AnkleRod_B | chrome-plated steel | cut Ø8 rod to length, tap M5x12 both ends | 2 | [JX1_AnkleRod_B.STEP](../manufacturing/step/JX1_AnkleRod_B.STEP) | - |
| JX1_Torso | 6061-T6 + 2020 | laser 5/4 mm plates + 4x 2020 extrusion posts (FEA SF 4.44/3.59) | 1 | [JX1_Torso.STEP](../manufacturing/step/JX1_Torso.STEP) | [pdf](../manufacturing/drawings/JX1_Torso.pdf) |
| JX1_ShoulderPitchBracket_L | 6061-T6 | laser 5 mm plates, bolted U-bracket (FEA SF 2.17/1.75) | 1 | [JX1_ShoulderPitchBracket_L.STEP](../manufacturing/step/JX1_ShoulderPitchBracket_L.STEP) | [pdf](../manufacturing/drawings/JX1_ShoulderPitchBracket_L.pdf) |
| JX1_ShoulderPitchBracket_R | 6061-T6 | as L, mirrored | 1 | [JX1_ShoulderPitchBracket_R.STEP](../manufacturing/step/JX1_ShoulderPitchBracket_R.STEP) | - |
| JX1_ShoulderRollBracket_L | 6061-T6 | laser 6 mm plates, bolted L-bracket (FEA SF 2.05/1.66) | 1 | [JX1_ShoulderRollBracket_L.STEP](../manufacturing/step/JX1_ShoulderRollBracket_L.STEP) | [pdf](../manufacturing/drawings/JX1_ShoulderRollBracket_L.pdf) |
| JX1_ShoulderRollBracket_R | 6061-T6 | as L, mirrored | 1 | [JX1_ShoulderRollBracket_R.STEP](../manufacturing/step/JX1_ShoulderRollBracket_R.STEP) | - |
| JX1_UpperArm_L | 6061-T6 | laser 10 + 8 mm plates + 2x 6 mm gussets, bolted/welded (FEA SF 3.12/2.52) | 1 | [JX1_UpperArm_L.STEP](../manufacturing/step/JX1_UpperArm_L.STEP) | [pdf](../manufacturing/drawings/JX1_UpperArm_L.pdf) |
| JX1_UpperArm_R | 6061-T6 | as L, mirrored | 1 | [JX1_UpperArm_R.STEP](../manufacturing/step/JX1_UpperArm_R.STEP) | - |
| JX1_Forearm_L | 6061-T6 | laser 6 mm plates, bolted (FEA SF 3.27/2.65) | 1 | [JX1_Forearm_L.STEP](../manufacturing/step/JX1_Forearm_L.STEP) | [pdf](../manufacturing/drawings/JX1_Forearm_L.pdf) |
| JX1_Forearm_R | 6061-T6 | as L, mirrored | 1 | [JX1_Forearm_R.STEP](../manufacturing/step/JX1_Forearm_R.STEP) | - |
| JX1_Head | PETG-CF, 3 walls, 25 % gyroid | FDM print (P1S) | 1 | [JX1_Head.stl](../manufacturing/print/JX1_Head.stl) | - |
| JX1_NeckBracket | PA-CF, solid | FDM print (P1S) | 1 | [JX1_NeckBracket.stl](../manufacturing/print/JX1_NeckBracket.stl) | - |
| JX1_Gripper | PA-CF body + TPU pads | FDM print (P1S) | 2 | [JX1_Gripper.stl](../manufacturing/print/JX1_Gripper.stl) | - |

## Fit-check prints (PETG) — NOT structural

Full-size copies of the metal parts (`fit_check/*_FITCHECK.stl`, part frame, mm) for checking actuator bolt patterns,
pilots, clearances and cable routes on the real actuators before ordering metal. Plain PETG, 3 walls, 15 % infill is enough.
**Never load them or stand the robot on them**: the printed leg/pelvis parts failed the FEA (SF 0.08-0.90 vs 2.0 required,
`calculations/results/structural/`).

| Part | STL |
|---|---|
| JX1_HipYawBracket_L | [JX1_HipYawBracket_L_FITCHECK.stl](fit_check/JX1_HipYawBracket_L_FITCHECK.stl) |
| JX1_HipYawBracket_R | [JX1_HipYawBracket_R_FITCHECK.stl](fit_check/JX1_HipYawBracket_R_FITCHECK.stl) |
| JX1_HipRollBracket_L | [JX1_HipRollBracket_L_FITCHECK.stl](fit_check/JX1_HipRollBracket_L_FITCHECK.stl) |
| JX1_HipRollBracket_R | [JX1_HipRollBracket_R_FITCHECK.stl](fit_check/JX1_HipRollBracket_R_FITCHECK.stl) |
| JX1_Thigh_L | [JX1_Thigh_L_FITCHECK.stl](fit_check/JX1_Thigh_L_FITCHECK.stl) |
| JX1_Thigh_R | [JX1_Thigh_R_FITCHECK.stl](fit_check/JX1_Thigh_R_FITCHECK.stl) |
| JX1_Shin_L | [JX1_Shin_L_FITCHECK.stl](fit_check/JX1_Shin_L_FITCHECK.stl) |
| JX1_Shin_R | [JX1_Shin_R_FITCHECK.stl](fit_check/JX1_Shin_R_FITCHECK.stl) |
| JX1_Foot_L | [JX1_Foot_L_FITCHECK.stl](fit_check/JX1_Foot_L_FITCHECK.stl) |
| JX1_Foot_R | [JX1_Foot_R_FITCHECK.stl](fit_check/JX1_Foot_R_FITCHECK.stl) |
| JX1_Pelvis | [JX1_Pelvis_FITCHECK.stl](fit_check/JX1_Pelvis_FITCHECK.stl) |
| JX1_AnkleCrank | [JX1_AnkleCrank_FITCHECK.stl](fit_check/JX1_AnkleCrank_FITCHECK.stl) |
| JX1_AnkleCross | [JX1_AnkleCross_FITCHECK.stl](fit_check/JX1_AnkleCross_FITCHECK.stl) |
| JX1_AnkleRod_A | [JX1_AnkleRod_A_FITCHECK.stl](fit_check/JX1_AnkleRod_A_FITCHECK.stl) |
| JX1_AnkleRod_B | [JX1_AnkleRod_B_FITCHECK.stl](fit_check/JX1_AnkleRod_B_FITCHECK.stl) |
| JX1_Torso | [JX1_Torso_FITCHECK.stl](fit_check/JX1_Torso_FITCHECK.stl) |
| JX1_ShoulderPitchBracket_L | [JX1_ShoulderPitchBracket_L_FITCHECK.stl](fit_check/JX1_ShoulderPitchBracket_L_FITCHECK.stl) |
| JX1_ShoulderPitchBracket_R | [JX1_ShoulderPitchBracket_R_FITCHECK.stl](fit_check/JX1_ShoulderPitchBracket_R_FITCHECK.stl) |
| JX1_ShoulderRollBracket_L | [JX1_ShoulderRollBracket_L_FITCHECK.stl](fit_check/JX1_ShoulderRollBracket_L_FITCHECK.stl) |
| JX1_ShoulderRollBracket_R | [JX1_ShoulderRollBracket_R_FITCHECK.stl](fit_check/JX1_ShoulderRollBracket_R_FITCHECK.stl) |
| JX1_UpperArm_L | [JX1_UpperArm_L_FITCHECK.stl](fit_check/JX1_UpperArm_L_FITCHECK.stl) |
| JX1_UpperArm_R | [JX1_UpperArm_R_FITCHECK.stl](fit_check/JX1_UpperArm_R_FITCHECK.stl) |
| JX1_Forearm_L | [JX1_Forearm_L_FITCHECK.stl](fit_check/JX1_Forearm_L_FITCHECK.stl) |
| JX1_Forearm_R | [JX1_Forearm_R_FITCHECK.stl](fit_check/JX1_Forearm_R_FITCHECK.stl) |

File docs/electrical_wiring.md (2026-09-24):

# JX1 electrical wiring (v0.4, 2026-09-24)

Scope: power distribution, CAN harness, logic power, E-stop circuit, hub pin map and harness routing. Architecture and
safety rationale: [architecture.md](architecture.md), [safety_architecture.md](safety_architecture.md). Actuator
connector facts are VERIFIED from the RobStride manuals (rev. 260713): **one XT30 power input** (board XT30APW-M, cable
XT30UW-F) and **one JST-GH 1.25 2-pin CAN connector (CAN-H, CAN-L; no ground pin — reference via the power return)** per
actuator. Nothing here has been built; wire gauges and fuse sizes are CALCULATED from the power budget
(`calculations/results/iter1_B_knee_and_pitch_RS04/power_budget.json`).

## 1. Power tree

```mermaid
flowchart LR
  subgraph Pack[Battery bay - torso]
    B[13S2P Samsung 50S<br/>41.6-54.6 V, 468 Wh] --> BMS[JBD SP14S004 BMS<br/>40 A]
  end
  BMS -- 10 AWG --> XT[XT90-S anti-spark<br/>service disconnect]
  XT -- 10 AWG --> SW[Flipsky anti-spark switch<br/>MOSFET, remote-off input]
  ES[E-stop XB2BS8442C<br/>NC contact] -. opens enable loop .-> SW
  SW -- 10 AWG --> PDB[Power distribution bar<br/>4 x ATO 30 A 58 V]
  PDB -- F1 12 AWG --> LL[Left leg trunk<br/>6 actuators]
  PDB -- F2 12 AWG --> RL[Right leg trunk<br/>6 actuators]
  PDB -- F3 12 AWG --> UA[Arms + waist trunk<br/>9 actuators]
  PDB -- F4 16 AWG --> AUX[Aux: DDR-60L-5 5 V 10.8 A<br/>+ adjustable buck set to 7.4 V]
  AUX --> J[Jetson Nano 5 V 4 A]
  AUX --> H[Hub board 5 V<br/>2 x Teensy 4.1]
  AUX --> SV[ST3215 servo bus 7.4 V<br/>neck x2, grippers x2]
```

| Segment | Current basis | Conductor | Protection | Label |
|---|---|---|---|---|
| Pack → BMS → XT90-S → switch → bar | 23 A peak (967 W at 41.6 V, fast gait), 40 A BMS continuous limit | 10 AWG silicone, ≤ 250 mm | BMS 40 A electronic | CALCULATED |
| Leg trunk F1 / F2 | ≤ 11 A per leg at the fast-gait peak (≈ 45 % of 967 W); transients to 30 A | 12 AWG silicone trunk | ATO 30 A **58 V** (Littelfuse 0891030.NXS) | CALCULATED |
| Arms + waist trunk F3 | 4 × RS02 + 4 × RS00 + RS06; ≤ 6 A typical, 20 A worst transient | 12 AWG | ATO 30 A 58 V | CALCULATED |
| Actuator drop (trunk splice → XT30UW-F) | single actuator DC current ≤ 15 A (RS04 ≈ 600 W mechanical at 42 V) | 16 AWG, ≤ 300 mm | trunk fuse | CALCULATED |
| Aux F4 | DDR-60L-5 60 W + 7.4 V servo buck ≤ 40 W → ≤ 3 A at 41.6 V | 16 AWG | ATO 30 A 58 V (conductor-limited: fit 5 A) | CALCULATED |

Rules: 32 V automotive fuses are **not** acceptable on the 54.6 V bus; every trunk is a spliced daisy chain (solder +
adhesive heat-shrink, or Wago-style 221 splices inside the pelvis/torso only); drops are strain-relieved at the actuator
with a P-clip to the bracket; all 48 V wiring is silicone-insulated (flex at joints) with red/black colour coding.

## 2. CAN harness (6 buses, classic CAN 1 Mbit/s, 29-bit IDs)

| Hub / bus | Nodes in chain order (CAN ID) | Chain length | Termination |
|---|---|---|---|
| A / CAN1 | L hip yaw (11) → L hip roll (12) → L hip pitch (13) | ≈ 0.6 m | 120 Ω on the hub board + 120 Ω at L hip pitch |
| A / CAN2 | L knee (14) → L ankle A (15) → L ankle B (16) | ≈ 1.1 m | hub + L ankle B |
| A / CAN3 | waist (31) → L shoulder pitch (21) → roll (22) → yaw (23) → elbow (24) | ≈ 1.0 m | hub + L elbow |
| B / CAN1 | R hip yaw (41) → R hip roll (42) → R hip pitch (43) | ≈ 0.6 m | hub + R hip pitch |
| B / CAN2 | R knee (44) → R ankle A (45) → R ankle B (46) | ≈ 1.1 m | hub + R ankle B |
| B / CAN3 | R shoulder pitch (51) → roll (52) → yaw (53) → elbow (54) | ≈ 0.9 m | hub + R elbow |

IDs, bus assignment, motor signs and limits are generated from the kinematic contract and the verified CAD
(`tools/gen_firmware_config.py` → `firmware/hub/jx1_hub/config_hub_{a,b}.h`). Twisted pair (≈ 33 twists/m, 26 AWG), stub from
the trunk to each GH1.25 ≤ 0.15 m. **Ground reference:** the RobStride CAN connector has no ground pin, so the hub board's
logic ground is tied to the battery negative at a single star point on the power bar (keeps the TJA1462 common-mode range
−12…+12 V). Bus load at 500 Hz with ≤ 3 leg joints per bus ≈ 45 % (5 arm joints: ≈ 75 %, arms run at 250 Hz).

## 3. Hub board (JX1 carrier PCB, 2 × Teensy 4.1)

| Signal | Teensy 4.1 pin | Hub A | Hub B | Notes |
|---|---|---|---|---|
| CAN1 TX/RX | 22 / 23 | left hip | right hip | TJA1462AT, 120 Ω jumper |
| CAN2 TX/RX | 1 / 0 | left knee + ankle | right knee + ankle | TJA1462AT |
| CAN3 TX/RX | 31 / 30 | left arm + waist | right arm | TJA1462AT (CAN-FD capable controller, used as classic CAN) |
| E-stop sense | 2 (INPUT_PULLUP) | ✓ | ✓ | E-stop auxiliary NC contact to GND: **HIGH = pressed or wire broken → damping** (fail-safe) |
| IMU BNO085 | SPI0 10/11/12/13 + INT 9 | ✓ | — | 400 Hz rotation vector |
| Servo bus | Serial1 1-wire half duplex via SmartElex bus-servo driver | — | ✓ | ST3215 neck yaw/pitch (+ grippers, phase 3) at 7.4 V |
| FSR foot pads | A0–A3 (+ A4–A7 hub B) | ✓ | ✓ | phase 2, 4 per foot |
| Host | native USB 480 Mbit/s | ✓ | ✓ | to the Jetson (binary protocol with CRC16, `firmware/hub/jx1_hub/jx1_hub.ino`) |

## 4. E-stop circuit (fail-safe, two independent paths)

1. **Power path:** the XB2BS8442C NC contact is wired in series with the Flipsky anti-spark switch's remote on/off loop — pressing
   (or a broken wire) opens the loop and the switch removes the 48 V motor bus. The logic rail (DDR-60L-5 on F4, upstream of
   the switch? **no** — F4 is fed from the bar **downstream** of the switch only for the servo buck; the Jetson/hub 5 V supply is
   fed **upstream** of the switch through its own 5 A fuse so that logging and state estimation survive an E-stop).
2. **Signal path:** a second NC contact block on the same operator (XB2 accepts stacked contact blocks) drives both hubs' pin 2;
   the firmware switches every joint to damping (Kd = 2 N·m·s/rad) and latches until the host re-arms.

Expected behaviour: the robot goes limp within one 2 ms bus period (signal path) and loses motor power within the switch's
turn-off time (power path). **All bring-up happens on a gantry/harness** ([safety_architecture.md](safety_architecture.md)).

## 5. Routing through joints

| Joint | Cable path | Provision |
|---|---|---|
| Hip yaw (±45°) | trunk passes through the Ø24 bore in the pelvis top plate above each hip | 90 mm service loop, spiral wrap |
| Hip roll / pitch | along the back of the hip-yaw bracket keel, then down the hip-roll back plate | loops sized for −25…45° roll and −115…35° pitch; P-clips on the aluminium plates |
| Knee (0…120°) | along the thigh's back flange, loop behind the knee housing (connector zones face backwards) | ≥ 100 mm loop; no cable in the knee pinch zone |
| Ankle | along the shin web to motors A/B; nothing crosses the ankle joint (motors are on the shin) | — |
| Waist (±90°) | centre Ø30 bore in the pelvis top plate / Ø14 in the torso bottom plate | clock-spring loop, 1.5 turns |
| Shoulders / elbows | along the shoulder brackets and upper-arm plates | spiral wrap; loops sized for the full CAD ranges |
| Neck | through the deck Ø20 hole to the ST3215 chain | 7.4 V + half-duplex data 3-wire servo cable |

## 6. Bring-up checklist (electrical)

1. Continuity + insulation test of every trunk before any actuator is connected; verify 58 V fuses fitted.
2. Pack on the bench through the BMS with a current-limited supply for the first power-up of the power bar.
3. One actuator at a time on the bench USB-CAN adapter (Waveshare USB-CAN-A): set CAN ID, read feedback, check fault flags.
4. Hub A with one bus populated; confirm 120 Ω termination (60 Ω measured across CAN-H/CAN-L with power off).
5. E-stop test: both paths (motor bus drops, hubs report `estop` and damping) before any leg is powered on the robot.

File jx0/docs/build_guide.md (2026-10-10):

# JX0 build guide

JX0 is 22 printed parts, 17 Feetech STS3215 servos (every joint, like the reference robot), a Raspberry Pi and a
handful of small modules. Everything is in the [parts list](../bom/jx0_bom.csv): ₹58,215 from Indian online stores,
with prices checked 2026-10-04. Budget two weekends for printing and one for assembly and bring-up.

Order of work: **buy → print → servo IDs → assemble → wire → bring-up → software**.

## How the legs are built (v0.4)

Every leg pitch and roll joint is **double-sided**, like the reference robot. The STS3215 is a dual-shaft servo
(Evelta sells it as "ST3215-C018 … Dual Shaft"): the output horn on one face and a passive hub on the other.

- The servo's **body sits in a cage** on one part (four walls and a plate the case is screwed to).
- The **next part is a U-bracket** that bolts to both faces: 4 screws into the horn, and 4 screws through a raised
  boss into the rear hub.

So the joint's load goes through both ends of the servo instead of bending its output shaft. With the simulated
walking loads, a one-plate joint (v0.3) would stress its plate past PETG's fatigue strength at every leg joint; the
U-brackets keep every printed leg part at a fatigue safety factor of 2.1 or more (finite elements:
[verification](../results/verification.md)).

The **hip yaw** cannot be a U-bracket: its servo stands under the body with the hip-roll servo right below it. Instead
the pelvis holds the yaw disc from both sides:
- a **thrust ring** above it, part of the pelvis;
- a **keeper** below it, a small printed C-shaped part whose lip runs under the disc's 3 mm flange. Four screws clamp
  it to a boss on the pelvis.

So the leg's bending goes from the disc into the pelvis, and the yaw servo's shaft is left with almost none of it. The
hip yaw turns ±12°, more than twice what the gaits use.

## 1. Print

STL files: `jx0/cad/stl/` (millimetres). The parametric SolidWorks parts are in `jx0/cad/parts/`. All the geometry is
generated from `jx0/cad/geometry.py`, so a change there rebuilds every part. To see a change before rebuilding it in
SolidWorks, run `python jx0/cad/preview.py`.

**Leg parts and pelvis: PETG, near-solid.** These carry every step:
- 0.2 mm layers, **6 walls, 6 top and 6 bottom layers, 40 % gyroid**, so their 2.4–4.5 mm plates print solid, as
  the strength check assumes;
- 235–245 °C nozzle, 75–85 °C bed;
- print each U-bracket lying on one of its arms, with tree supports under the other arm.

**Body, head and arms: PLA.** The reference robot's pastel green is closest to eSun PLA-Matte Mint Green. Use
0.2 mm layers, 3 walls, 25 % gyroid, 205–215 °C nozzle and a 60 °C bed.

**Print one U-bracket first** (a shin is the smallest) and fit a servo:
- the horn and hub must sit flat on the bracket's arms;
- the boss must slide over the cage's plate.

The screw holes are sized for M2 self-tapping screws, and the hub's 4-hole pattern is ASSUMED equal to the horn's.
Neither is published for the STS3215.

| Part | Qty | Printed mass | Size (mm) | Material, print tip |
|---|---|---|---|---|
| JX0_Pelvis (two hip-yaw cages, thrust rings, keeper bosses) | 1 | 77.9 g | 52 × 139 × 39 | PETG near-solid; top plate down |
| JX0_YawKeeper_L / _R | 1 + 1 | 2.8 g each | 31 × 42 × 8 | PETG near-solid; flat top down |
| JX0_HipYawBracket_L / _R | 1 + 1 | 50.0 g each | 70 × 58 × 46 | PETG near-solid; disc face down, supports in the groove |
| JX0_HipRollBracket_L / _R | 1 + 1 | 29.0 g each | 96 × 54 × 31 | PETG near-solid; rear arm down |
| JX0_Thigh_L / _R | 1 + 1 | 44.3 g each | 52 × 48 × 92 | PETG near-solid; outer arm down |
| JX0_Shin_L / _R | 1 + 1 | 25.2 g each | 31 × 48 × 84 | PETG near-solid; outer arm down |
| JX0_AnkleBracket_L / _R | 1 + 1 | 35.9 g each | 72 × 61 × 33 | PETG near-solid; outer arm down |
| JX0_Foot | 2 | 51.1 g each | 124 × 70 × 46 | PETG near-solid; sole down |
| JX0_Torso (lower shell with the skirt) | 1 | 103.4 g | 84 × 120 × 136 | PLA; floor down |
| JX0_ChestCap | 1 | 46.4 g | 84 × 126 × 42 | PLA; upside down (top face on the bed), chamfers 45° |
| JX0_Head | 1 | 66.8 g | 66 × 78 × 62 | PLA; upright on its floor, tree supports inside the rounded top |
| JX0_UpperArm_L / _R (shoulder hood + elbow box) | 1 + 1 | 22.7 g each | 53 × 35 × 84 | PLA; outer plate down |
| JX0_ArmBlade_L / _R | 1 + 1 | 15.3 g each | 36 × 8 × 116 | PLA; lying flat |
| **Total** | **22** | **847 g** | | 555 g PETG + 293 g PLA |

## 2. Before assembly: servo IDs and centring

Every STS3215 ships as ID 1. Set the IDs one servo at a time and write each on its case. The table is in
[wiring.md](wiring.md): legs 1–12, arms 13–16, neck 17. Then chain the servos, run
`python -m jx0bot.calibrate center`, and fit every horn and bracket while the servos hold mid-travel.
[bringup.md](bringup.md) has the commands.

## 3. Assemble

Two rules at every leg joint:
- **The servo goes into its cage from the open side** (with its horn off where a plate covers that side), and its
  case screws go in through the cage's plate. The holes in a bracket's arm let a screwdriver reach the far ones.
- **The U-bracket slides onto the servo from below**, its boss gliding over the cage's plate onto the rear hub. The
  near case screw on that side is left out on purpose, so the boss can pass; three screws and the cage walls hold the
  case. Then 4 screws go into the horn and 4 through the boss into the hub.

All three hip axes meet at the hip centre and both ankle axes at the ankle centre, as the walking model assumes.

Legs, top down (left shown; the right is the mirror image):

1. **Pelvis.** Slide each hip-yaw servo into its pelvis cage from below, horn end down, and screw it through the top
   plate (4 × M2 × 6, heads sunk). Fit the yaw horn.
2. **Hip-yaw bracket and keeper.**
   - Slide the hip-roll servo into the bracket's cage from the front, horn off, and screw it through the back plate.
   - Put one layer of PTFE tape on the top of the disc and one under its flange (the rim above the groove).
   - Bolt the disc to the yaw horn from below (4 × M2 × 10 through the sunk holes). It rides 0.1 mm under the
     pelvis's thrust ring.
   - Slide the **keeper** in sideways from the outer front of the hip, its lip into the groove under the disc's
     flange, and clamp it flat against the pelvis's boss with 4 × M2 × 10 from below.
   - Turn the leg by hand: it must turn freely through ±12° with no up-and-down wobble at the disc's rim. If it wobbles,
     add a layer of PTFE tape under the flange; if it binds, take one off. Do this before fitting anything below.
3. **Hip-roll bracket.** First fit it to the hip-roll servo, horn on:
   - slide it on from below, rear boss over the cage's back plate;
   - put the 4 horn screws in from inside its empty pitch cage (heads sunk), then 4 × M2 × 10 into the hub.

   Then slide the hip-pitch servo into the pitch cage from the outer side and screw it through the inner plate.
4. **Thigh.**
   - Slide the knee servo into the thigh's knee cage from the front (horn off). Put in its near case screw through the
     inner plate, and the two far ones through the holes in the inner arm. Fit the knee horn.
   - Slide the thigh onto the hip-pitch servo from below: 4 × M2 × 8 into the horn, 4 × M2 × 10 into the hub.
5. **Shin.**
   - Slide the ankle-pitch servo up into the shin's cage from below. The front near screw goes in sunk (the rear
     one is left out on purpose: that corner has no side wall, and a hole there would weaken the plate beside the
     hub); the far ones go through the holes in the inner arm.
   - Slide the shin onto the knee servo from below.
6. **Ankle bracket.**
   - Slide the ankle-roll servo into its cage from the inboard end (horn off) and screw it through the back plate.
   - Fit the roll horn through the rim's hole.
   - Slide the bracket onto the ankle-pitch servo from below.
7. **Foot** onto the ankle-roll servo from below, heel arm over the cage's back plate. Glue the 1 mm rubber sheet
   under the sole (contact cement) and trim it flush.

Body, arms and head:

8. **Lower torso** onto the pelvis: 4 × M3 × 8 into heat-set inserts pressed into the pelvis (soldering iron at about
   220 °C). Its skirt comes down around the two hip-yaw servos. Inside:
   - the Raspberry Pi on the back-wall standoffs;
   - the battery on the floor, with the servo driver and the UBEC beside it;
   - the push-to-talk button in the back wall.

   The leg cables come up through the slot in the floor.
9. **Arms**, each side:
   - Shoulder servo into the hood, case down, screwed to the outer plate.
   - Elbow servo into the box below, horn outward, screwed to the inner plate.
   - Blade onto the elbow horn (4 × M2 × 12).
10. **Chest cap**:
    - Screw the **neck servo** onto the top by its rear face, horn up.
    - Fit the speaker under the round grille.
    - Bolt each **shoulder horn** to its pad on the cap's side wall from inside the cap (4 × M2 × 10); the arm now
      hangs from the pad.
    - Slide the cap over the torso lip and fix it with 4 screws through the cap wall, front and back.
11. **Head** onto the neck horn (centre screw + 4 horn screws). Glue the microphone behind the four face holes and take
    its cable down through the hole in the head floor, with slack for ±80° of head turn.

Look at `jx0/cad/JX0_Robot.SLDASM` in SolidWorks, or the pictures in [../README.md](../README.md), whenever a
part's orientation is unclear.

## 4. Wire, bring up, install the software

- [wiring.md](wiring.md): power, the servo bus chains and IDs, the GPIO map.
- [bringup.md](bringup.md): IDs, centring, zero pose, directions, stiffness, first stand and first steps.
- [software_setup.md](software_setup.md): Raspberry Pi OS, audio, voice models, the Claude API key, start on boot.

## Fasteners and small parts

| Item | Where | Notes |
|---|---|---|
| M2 × 6 socket screws (66) | servo cases (3 or 4 per servo), hip-roll horns | size ASSUMED: fit-check on the first bracket |
| M2 × 8 (36) | U-bracket horn arms, head | |
| M2 × 10 (64) | U-bracket hub arms through the boss, hip-yaw discs, hip-yaw keepers, shoulder pads | |
| M2 × 12 (8) | arm blades | |
| M3 × 8 socket screws (8) + M3 heat-set inserts | torso to pelvis, chest cap to torso | |
| PTFE thread-seal tape | top of each hip-yaw disc and under its flange: layers set the keeper's play (or silicone grease) | |
| 1 mm rubber sheet | foot soles | any thin anti-slip mat works |
| Hot glue, zip ties, double-sided foam tape | microphone, battery, wiring | |

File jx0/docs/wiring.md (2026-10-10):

# JX0 wiring

All 17 joints are the same Feetech STS3215 12 V serial bus servo, like the reference robot, so the wiring is short:
one serial bus for every servo, one 5 V converter for the Raspberry Pi, and a few small audio and IMU modules.

## Power

```mermaid
flowchart LR
  BAT["3S LiPo 11.1 V 2200 mAh (XT60)<br/>or a 12.6 V bench supply"] --> SW["10 A toggle switch"]
  BAT -. balance lead .-> ALARM["LiPo voltage alarm"]
  SW --> DRV["Waveshare serial bus servo driver<br/>DC in 9-12.6 V"]
  DRV --> BUS["17 x STS3215<br/>legs, arms, neck"]
  SW --> UBEC["UBEC 5 V 5 A"] --> PI["Raspberry Pi 4<br/>5 V pins 2 + 4, GND pin 6"]
  PI -- USB --> DRV
```

| Run | Wire | Why |
|---|---|---|
| Battery → switch → servo driver | 16 AWG silicone | the servos together can pull a few amps while walking |
| Switch → UBEC | 20 AWG | under 2 A |
| UBEC → Pi 5 V (pins 2 and 4) and GND (pin 6) | 20 AWG | 5 V on the GPIO pins bypasses the Pi's input fuse, so double-check the polarity before you plug in |

- **Bench supply (how the reference robot is run):** set it to 12.6 V and a 3 A current limit, and plug it into the
  same XT60 instead of the battery. On the reference robot's supply display, a robot like this draws 0.6–1.5 A at 12.6 V
  (about 7–19 W) while walking. That lets you test for hours without charging.
- Plug the voltage alarm into the LiPo's balance lead and set it to about 3.5 V per cell. Stop when it beeps: running a
  LiPo flat ruins it.
- Charge with the B3 charger only, never unattended, and on a non-flammable surface.

## The servo bus

Every STS3215 has two identical 3-pin connectors, so the servos chain one into the next, and every servo on the bus
has its own ID, so one driver board runs all 17. The board has two servo ports (both are the same bus), so use two
chains:

| Port | Chain (bus ID) |
|---|---|
| 1 | left leg: hip yaw 1 → hip roll 2 → hip pitch 3 → knee 4 → ankle pitch 5 → ankle roll 6 |
| 2 | arms and neck, then the right leg: left shoulder 13 → left elbow 14 → neck 17 → right shoulder 15 → right elbow 16 → (a servo extension down through the torso floor) → right hip yaw 7 → hip roll 8 → hip pitch 9 → knee 10 → ankle pitch 11 → ankle roll 12 |

Feed the board's power through its green screw terminal with the 16 AWG wire, not the 5.5 × 2.1 mm barrel jack: in
simulation the 17 servos draw about 1 A on average while walking and about 2 A in short peaks, more when they push
hard.

The IDs are in `jx0/software/jx0bot/config.yaml`. Every servo ships as ID 1, so set them with `calibrate.py set-id`,
**one servo at a time** (see [bringup.md](bringup.md)). Connect the driver board to the Pi by USB; the Pi sees it as
`/dev/ttyUSB0` or `/dev/ttyACM0` (set `bus.port` in config.yaml). Set the board's mode jumper for USB/serial pass-through,
as the Waveshare wiki for the board describes.

Arm and neck cables: each shoulder servo hangs outside the chest in its arm's hood. Its cable and the elbow servo's run
together from the hood into the chest cap through the gap under the cap's side chamfer, with enough slack for the arm
to swing up in front (zip-tie them to the hood so the blade cannot catch them). The neck cable goes in through the gap
next to the neck servo. Leg cables: up the back of each leg, zip-tied to the brackets, into the torso through the slot
in its floor; leave a loop at every joint for its full range.

## Raspberry Pi GPIO map (BCM numbers, physical pin in brackets)

| Function | GPIO (pin) | Connects to |
|---|---|---|
| 3.3 V | (1), (17) | MPU6050 VCC, INMP441 VDD |
| 5 V in | (2), (4) | UBEC + |
| GND | (6), (9), (14), (20), (25), (30), (34), (39) | all grounds |
| I2C SDA / SCL | 2 (3) / 3 (5) | MPU6050 SDA / SCL |
| Push-to-talk button | 17 (11) | button to GND (internal pull-up) |
| I2S bit clock | 18 (12) | INMP441 SCK and MAX98357A BCLK |
| I2S word select | 19 (35) | INMP441 WS and MAX98357A LRC |
| I2S data in | 20 (38) | INMP441 SD (L/R pin to GND = left channel) |
| I2S data out | 21 (40) | MAX98357A DIN (Vin from 5 V, speaker on + / −) |

The servos need no GPIO at all: they're all on the USB servo bus.

## Where things sit

- **Lower torso:** the Raspberry Pi on the 4 standoffs on the back wall, the battery on the floor, the servo driver and
  the UBEC beside it. The push-to-talk button goes in the hole in the back wall, and the leg cables come up through the
  slot in the floor.
- **Chest cap:** the speaker under the round grille on top and the neck servo standing on top. The two shoulder
  servos are in the arms' hoods, their horns bolted to the pads on the cap's side walls.
- **Pelvis:** the MPU6050, as close to the hip centre as you can, **x arrow forward, y arrow to the robot's left**
  (otherwise set `imu.mount` in config.yaml).
- **Head:** the INMP441 microphone glued behind the four face holes. Its cable goes down through the hole in the head
  floor, with a loop of slack for the ±80° neck turn.

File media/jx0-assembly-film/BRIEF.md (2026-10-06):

---
workflow: general-video
flow: automation
storyboard: no
message: "Anyone can build JX0 — here is how its parts go together, and it walks"
destination: github-readme
aspect: 1920x1080
language: en
audience: students and makers who want to build a small walking, talking humanoid at home
length: about 60s
angle: animated assembly guide, the JX0 sibling of the JX1 film (media/assembly-film)
---

## Intent

The user asked for the JX1 assembly video's equivalent for JX0: "like the assembly video of jx1 i need for jx0 also".
Every SolidWorks part of JX0 flies into place in the order of the build guide, the camera follows the build, and the
finished robot walks its verified gait.

## Assets

- assets/footage.mp4 — 3D assembly footage rendered from the SolidWorks STL meshes (jx0/cad/stl) by
  tools/media/assembly_film_jx0.py (MuJoCo renderer, 1920x1080, 30 fps). The motion lives here.
- ../jx0_assembly/timeline.json — segment times (intro, explode, 13 steps, finale, walk) the titles sync to.

## Customizations

- Same design system as the JX1 film: step cards (step n / 13, section, real specs), build-progress bar, opening
  title, parts-count explode beat, finale stats, "and it walks" title, end card with the repo URL.

## Notes

- index.html is generated by tools/media/build_assembly_composition.py --robot jx0 — edit the generator, not the HTML.
- No music or voiceover (not asked for, as for JX1).
- Design: dark studio footage; League Gothic titles + IBM Plex Mono specs; cyan #3cc8ff matches the parts' arrival
  glow, orange #f26b1d is the JX0 brand dot (as in the cost estimate PDF).

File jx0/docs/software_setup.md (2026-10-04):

# JX0 software setup

JX0's program is `jx0/software/jx0bot`. It listens (Vosk, offline), thinks (Claude, over Wi-Fi), talks (Piper,
offline), and moves all 17 STS3215 joints over one serial bus: verified walking gaits with arm swing and IMU balance,
turning, waving, nodding and looking around.

## Try it on a PC first (no robot needed)

The same program drives the simulated JX0, so you can talk to the robot before you buy anything.

```bash
pip install -r jx0/software/requirements-pc.txt
```

```bash
cd jx0/software && python -m jx0bot.main --sim --text
```

A MuJoCo window opens with JX0 standing. Type things like "wave at me", "walk forward four steps", "look left" or
"turn around". You need an Anthropic API key in the environment (`ANTHROPIC_API_KEY`; see "The brain" below).

To render the demo film without a key: `python jx0/sim/demo_jx0.py`.

## On the robot (Raspberry Pi 4)

### 1. System

Flash **Raspberry Pi OS (64-bit, Bookworm)** with Raspberry Pi Imager and set Wi-Fi, a user and SSH in its options.
Then on the Pi:

```bash
sudo raspi-config nonint do_i2c 0 && sudo raspi-config nonint do_spi 0
```

Add to `/boot/firmware/config.txt` (I2S audio for the INMP441 microphone and the MAX98357A amplifier):

```
dtparam=i2s=on
dtoverlay=googlevoicehat-soundcard
```

This overlay is the one commonly used for an INMP441 + MAX98357A pair on the Pi's I2S pins. It is **UNVERIFIED on
JX0**: after a reboot, `arecord -l` and `aplay -l` should both list the card. A USB microphone and a USB speaker work as
a fallback with no overlay at all.

```bash
sudo apt install -y git python3-venv espeak-ng libportaudio2
```

### 2. Code and Python packages

```bash
git clone https://github.com/nickthelegend/thenar-jx1.git ~/thenar-jx1
```

```bash
python3 -m venv --system-site-packages ~/jx0env && source ~/jx0env/bin/activate
```

```bash
pip install -r ~/thenar-jx1/jx0/software/requirements-pi.txt
```

### 3. Voice models (offline)

Put both in `jx0/software/jx0bot/models/`:

- Speech recognition: **vosk-model-small-en-us-0.15** (about 40 MB) from the Vosk models page, alphacephei.com/vosk/models.
  Unzip it so the folder is `models/vosk-model-small-en-us-0.15/`.
- Voice: **en_US-lessac-medium** Piper voice (the `.onnx` file and its `.onnx.json`, about 60 MB) from the
  `rhasspy/piper-voices` repository on Hugging Face. Without it JX0 falls back to eSpeak-NG, which works but sounds
  robotic.

### 4. The brain (Claude)

JX0 sends what it hears to Claude and speaks the answer. Create an API key in the Anthropic Console, then on the Pi:

```bash
echo 'export ANTHROPIC_API_KEY=your-key-here' >> ~/.bashrc && source ~/.bashrc
```

Never commit the key to the repository. The model is `claude-opus-5` (set `JX0_MODEL` to use another one). Replies are
kept to one to three spoken sentences, so each answer costs very little.

### 5. Run

```bash
cd ~/thenar-jx1/jx0/software && python -m jx0bot.main
```

Hold the push-to-talk button (or say "hey robot"), speak, and let go. `--text` lets you type instead of talking, which
is handy over SSH. Do the [bring-up](bringup.md) first: the servo IDs, zero pose and directions must be in config.yaml
before the legs are powered.

### 6. Start on boot (optional)

`/etc/systemd/system/jx0.service`:

```ini
[Unit]
Description=JX0 robot
After=network-online.target

[Service]
User=pi
WorkingDirectory=/home/pi/thenar-jx1/jx0/software
Environment=ANTHROPIC_API_KEY=your-key-here
ExecStart=/home/pi/jx0env/bin/python -m jx0bot.main
Restart=on-failure

[Install]
WantedBy=multi-user.target
```

```bash
sudo systemctl enable --now jx0
```

## What each file does

| File | Job |
|---|---|
| `main.py` | wires everything together: listen, then think, then speak and move |
| `brain.py` | Claude conversation with streaming speech and the robot's tools (wave, nod, walk, turn, look) |
| `voice.py` | Vosk listener (button or wake phrase) and the Piper / eSpeak speaker |
| `robot.py` | joint I/O for the real robot or the simulation; gait playback (legs and arm swing) with IMU balance; all actions |
| `servo_bus.py` | Feetech STS serial protocol for the 17 STS3215 servos |
| `imu.py` | MPU6050 driver with a complementary filter |
| `calibrate.py` | servo IDs, centring, zero pose, joint directions, stiffness check (all 17 servos) |
| `config.yaml` | servo IDs, directions, zero ticks, limits, IMU, balance gains, push-to-talk pin |
| `gaits/*.json` | 100 Hz trajectories (legs and arm swing) that passed the closed-loop simulation check (`jx0/sim/walk_jx0.py`) |

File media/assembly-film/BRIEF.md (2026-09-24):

---
workflow: general-video
flow: automation
storyboard: no
message: "Anyone can build JX1 — here is how its 87 parts go together, and it walks"
destination: github-readme
aspect: 1920x1080
language: en
audience: makers, students and small labs who want to build a humanoid
length: 96s
angle: animated assembly guide
---

## Intent

An animated assembly of the whole JX1 humanoid we designed — not image by image: every CAD part flies into place
in build order, the camera follows the build, and the finished robot walks. The user asked: "i want animated..
assembly.. not just the image by image please make this", "anyone should be able to make robots", and for the
video to be made with HyperFrames.

## Assets

- assets/footage.mp4 — the 3D assembly footage rendered from the SolidWorks part meshes by
  tools/media/assembly_film.py (MuJoCo renderer, 1920x1080, 30 fps). The motion lives here.
- ../assembly/timeline.json — segment times (intro, explode, 22 steps, finale, walk) that the titles sync to.

## Customizations

- Step cards in sync with the footage (step n / 22, part names, real specs from the BOM/FEA), build-progress bar,
  opening title, "87 parts" explode beat, finale stats, "and it walks" title, end card with the repo URL.

## Notes

- Built autonomously on the user's "please make this" (no interview); no music or voiceover (not asked for).
- index.html is generated by tools/media/build_assembly_composition.py — edit the generator, not the HTML.
- Design: dark studio footage; League Gothic titles + IBM Plex Mono specs (both renderer-bundled); cyan #3cc8ff
  matches the parts' arrival glow, orange #f26b1d is the JX1 head colour.

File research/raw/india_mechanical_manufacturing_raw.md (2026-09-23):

# JX1 — India mechanical sourcing & manufacturing: RAW research log

- **Project:** JX1 low-cost compact humanoid (~1.2 m, 25–30 kg), built in India. FDM (Bambu P1S class: PETG, PETG-CF, PA-CF) + CNC aluminium only where justified.
- **Research date:** 2026-09-24 (all "VERIFIED" rows were read from the live page/API on this date).
- **Method:** curl/Python against store pages & public JSON: IndustryBuying (search-page `ng-state` JSON, PDP JSON-LD), Moglix (`ssr-pwa-state` JSON), Shopify stores Robocraze / ThinkRobotics / Quartz Components (`/search/suggest.json`, `/products/<handle>.js`; after HTTP 429 rate-limits some reads were done with WebFetch of the same JSON), WooCommerce store bearinghouse.in (`/wp-json/wc/store/products`), Robokits (Zen Cart listing HTML), SKF India e-Marketplace (page title/meta + its search-suggest endpoint), IndiaMART category pages (listing HTML; rate-limited after ~6 pages → leads only), Evelta (BigCommerce listing), WebSearch/WebFetch for services. robu.in, amazon.in, element14, digikey **not** checked (out of scope — covered elsewhere). Filament (§5) and manufacturing-service (§6) sweeps were run as parallel sub-tasks with the same rules.
- **Checked but not useful:** bearingkart.com/.in and bearingsdirect.in (domains do not resolve), rollon.in (parked domain), bearingmart.in / bearingstore.in (no public catalogue/price API), probots.co.in (Magento search returned unrelated items), electronicscomp.com (no bearing results), evelta.com (no bare magnets/mechanical stock).
- **No accounts, no forms submitted, no downloads.**

### Label legend
| Label | Meaning |
|---|---|
| **VERIFIED** | Price/stock seen on the live page or the store's own public JSON on 2026-09-24; URL given. |
| **ESTIMATED** | Derived number; math shown. |
| **UNVERIFIED** | Lead only (IndiaMART/TradeIndia listing, marketing blog, third-party claim, or price not visible in static HTML). Must be confirmed by phone/quote. |

### GST conventions seen
- **IndustryBuying (IB):** listing gives both *incl-GST* and *excl-GST* (GST 18 % on bearings/fasteners). Price is **per selling unit** (per piece, or per pack if title says "Pack of N"). "Min" = minimum order quantity of that unit — check it, some SKUs have MOQ 10–100 units.
- **Moglix:** `salesPrice` = incl GST, `priceWithoutTax` = excl GST; `moq`; `itemInPack`.
- **bearinghouse.in:** shows *excl. GST* and *incl. GST* explicitly (18 %).
- **Robocraze:** product pages state "Incl. GST (No Hidden Charges)".
- **Quartz Components / ThinkRobotics:** Shopify price as displayed; GST wording not present in static HTML → treated as **displayed price (GST status not stated)**; Indian Shopify retail prices are normally GST-inclusive, but confirm at checkout.
- **SKF India e-Marketplace:** price appears in page `<title>`/`og:title` ("at Best Price ₹X"); live price widget is JS-loaded, GST treatment **not visible** in static HTML.
- **Robokits:** product pages show "GST Input Tax Credit @ 18 % of ₹X available" where X = 18 % × displayed price (e.g. ₹315 rod → ₹56.7), i.e. the displayed price may be **ex-GST** (+18 % at checkout) — not confirmed; marked "not stated*".
- **IB GST exceptions:** springs listed at 5 % GST; everything else used here is 18 %.

---

## 0. BEST-VALUE PICKS (quick view; details & URLs in sections below)

| Need | Best-value credible pick (2026-09-24) | ₹ (incl GST unless noted) | Branded fallback |
|---|---|---|---|
| Thin-section 6804/6805/6806/6807/6808/6810/6908 | **FBJ 2RS/ZZ @ bearinghouse.in** (1-pc MOQ, in stock) | 111 / 132 / 165 / 192 / 276 / 470 / 276 | NTN 68xxJR (IB) 353–837; SKF 61805 domestic 261; KOYO 6807 530; SKF 61804-2RS1 1,066 (SKF e-Mkt) |
| 6000/6001/6002/608/625/626/688 | FBJ @ bearinghouse.in; Quartz/Robocraze for 608/625/626 | 30–53 | SKF 6000-2RS1 174 / 608-2RSH 264 (SKF e-Mkt) |
| Angular contact 7001/7002 | KOYO / NTN @ IB | 601 – 707 | SKF 7201/7202 BEP 1,396–1,413 |
| Crossed roller | none cheap: IKO CRBHV3510 / CRB4010 / CRB5013 @ IB | 11,799 – 15,339 | IndiaMART "THK RB3510" lead ₹4,200 (unverified) → **use paired 68xx instead** |
| Thrust / needle | N2K 51104 / 51106, HK0810 / HK1012; KHK AXK3047 @ bearinghouse | 34 – 118 | NBC 51104 152–169 |
| SHCS M3–M6 (bulk) | **Unbrako packs of 100 @ IB** (M3×8 = A2-70 SS) | 211–530 /100 (₹2.1–5.3/pc), 30-day lead | 12.9: Caparo M3×16 ₹896/200; TVS packs on Moglix |
| Heat-set inserts M3 | **Quartz** M3 brass (pack 10) | 33–70 /10 | ThinkRobotics M4/M5 80–100 /10 |
| Dowel pins 3/4/5 mm | CE solid dowel packs of 100 @ IB | 471 – 719 /100 | ThinkRobotics alloy 150–240 /10 |
| Linear shafts Ø5–Ø16 | **Robokits Astro hard-chrome rod, 1 m** | 220 – 450 /m (GST may be extra) | Robocraze SS rods 149–324 (short lengths) |
| Al 6061-T6 | IndiaMART stockists (plate ₹260–555/kg; bar ₹230–300/kg) — leads | – | retail cut plate ≈ ₹1,815/kg (IB Invento) |
| CF tube Ø20–28 | ThinkRobotics roll-wrapped 3K, 1 m | 1,620 – 2,160 | – |
| GT2 belt / pulleys | Robokits (₹46/m belt; 20T–80T pulleys) | 46 /m; 89–419 | IB Invento 4 m belt ₹931 |
| HTD 3M/5M | only Contitech/Optibelt @ IB, 120-day lead | 919+ belt; 3,539+ pulley | → print HTD pulleys, source belts elsewhere |
| Rod ends / ankle linkages | **N2K POS5/PHS5 (M5) @ bearinghouse**; GE12/GE15 spherical plain | 141.60; 159–177 | THK POS5 1,769 (IB) |
| Drag chain | Robokits 10×10 / 15×20 per metre | 215 / 356 | – |
| 2020 extrusion | **Robokits Astro 2020H** per metre | 341 /m | 4040 ₹876/m (pre-order) |
| Foot soles | 4 mm rubber anti-skid mat (Moglix) to cut, or print TPU 95A | 548 /mat | NBR sheet 3 mm 300×300 ₹1,084 (IB) |
| Filament PETG | **Numakers PETG-HS** ₹599 ex-GST (≈ ₹707 incl.) | ≈ 707 /kg | Bambu PETG HF refill ₹1,150 (Ideal3D) |
| Filament PETG-CF | **Numakers PETG-CF** ₹1,149 ex-GST (≈ ₹1,356 incl.) | ≈ 1,356 /kg | Bambu PETG-CF ₹1,599–1,900 — **OOS at all readable resellers** |
| Filament PA-CF | **eSUN PA-CF @ 3Idea** (in stock) | 4,799 /kg | Bambu PAHT-CF ₹6,299 (WOL3D, in stock); Bambu PA6-CF ₹4,999–5,000 (OOS) |
| Filament PLA / PLA+ | Numakers PLA ₹565 / PLA+ ₹600 ex-GST | ≈ 667–708 /kg | Bambu PLA Basic refill ₹1,149–1,150 |
| Filament TPU 95A | **Elegoo TPU 95A @ 3D Master India** | 1,399 /kg | Bambu TPU 95A HF ₹3,299–3,300 |
| Filament ASA | Numakers ASA ₹699 ex-GST (white/grey); black ₹891 incl. (Zbotic) | ≈ 825–891 /kg | Bambu ASA ₹1,999 (WOL3D) |
| PCB fab (5 pcs, 100×100, 2L) | **Lion Circuits** (public calculator) | ₹1,877 ex-GST (≈ ₹2,215 incl), ~5 d | PCB Power ₹5,210 ex-GST; JLCPCB $2 headline (app-only, duty/KYC) |
| Outsourced 3D printing | **iamRapid** published examples | PETG ≈ ₹17/g, CF-PETG ≈ ₹42/g, SLS/MJF PA12 ≈ ₹40/cm³ (ex-GST) | 3Ding (₹200 FDM / ₹2,000 MJF per-part minimum) |
| CNC aluminium | Makenica (instant quote, 1-pc MOQ, <5 d; FAQ anchor ₹7,000 for "1 part") / Robocon CNC (manual quote, in-house anodise) | no public per-part price | FabFlow/Custiv/Karkhana claims ₹450–1,200/bracket (unverified) |
| Laser cutting / bending | no Indian instant-quote site found; IndiaMART fibre-laser shops | ₹40–500 /sq ft, ₹150–200 /kg (unverified) | Manufyn / Custiv manual RFQ |
| Anodising | IndiaMART job shops | Type II ≈ ₹3.9–43 /dm² (unverified, lot charges extra) | Robocon in-house (in quote) |

---

## 1. BEARINGS

### 1a. Thin-section deep-groove (6700 / 6800 / 61800 / 6900 / 61900) — robot-joint output & cross-support bearings

Note: SKF/FAG name 6804 as **61804**, 6908 as **61908**, etc. Dimensions: 6804/61804 = 20×32×7; 6805 = 25×37×7; 6806 = 30×42×7; 6807 = 35×47×7; 6808 = 40×52×7; 6810 = 50×65×7; 6908/61908 = 40×62×12.

| Item | Brand/Model | Supplier | Price ₹ (incl GST) | GST | Qty | Stock / lead | Key specs | URL | Date | Evidence |
|---|---|---|---|---|---|---|---|---|---|---|
| 6804 | FBJ 6804-2RS (61804 2RS) | bearinghouse.in | 110.92 (ex 94.00) | 18% | 1 pc | In stock | 20×32×7, rubber sealed | https://bearinghouse.in/shop/fbj-6804-2rs-ball-bearing/ | 2026-09-24 | VERIFIED (Woo Store API) |
| 6804 | NBC 6804ZZ | bearinghouse.in | 276.12 (ex 234) | 18% | 1 pc | In stock | 20×32×7, metal shields | https://bearinghouse.in/shop/nbc-6804zz-ball-bearings/ | 2026-09-24 | VERIFIED |
| 6804 | NBC 6804ZZ | IndustryBuying | 294 (ex 249) | 18% | 1 pc, MOQ 2 | In stock, ships ≤4 d | 20×32×7 | https://www.industrybuying.com/deep-groove-ball-bearings-nbc-BEA.DEE.23230984 | 2026-09-24 | VERIFIED (IB search state) |
| 6804 | NTN 6804JR | IndustryBuying | 388 (ex 329) | 18% | 1 pc, MOQ 2 | In stock, ≤8 d | 20×32×7 open | https://www.industrybuying.com/deep-groove-ball-bearings-ntn-FAM163780 | 2026-09-24 | VERIFIED |
| 61804 | SKF 61804/C3 (Domestic) | IndustryBuying | 341 (ex 289) | 18% | 1 pc, MOQ 5 | In stock, ≤30 d | 20×32×7, C3 | https://www.industrybuying.com/deep-groove-ball-bearings-skf-FAM142190 | 2026-09-24 | VERIFIED |
| 61804 | UBC 61804 / 61804 ZZ / 61804 2RS | IndustryBuying | 67 (ex 57) | 18% | 1 pc, MOQ 10 | In stock, ≤3 d | 20×32×7 (generic brand) | https://www.industrybuying.com/deep-groove-ball-bearings-ubc-BEA.DEE.48613516 | 2026-09-24 | VERIFIED |
| 61804 | FAG 61804-HLC (imported) | IndustryBuying | 648 (ex 549) | 18% | 1 pc | In stock, ≤4 d | 20×32×7 | https://www.industrybuying.com/deep-groove-ball-bearings-fag-FAM156097 | 2026-09-24 | VERIFIED |
| 61804 | SKF 61804-2RS1 (imported) | bearinghouse.in | 1,329.86 (ex 1,127) | 18% | 1 pc | In stock | 20×32×7, 2RS1 | https://bearinghouse.in/shop/skf-61804-2rs1-6804-deep-groove-ball-bearing/ | 2026-09-24 | VERIFIED |
| 61804 | SKF 61804-2RS1 | SKF India e-Marketplace (official) | 1,066 (title price) | not shown | 1 pc | – | 20×32×7 | https://www.emarketplace.in.skf.com/deep-groove-ball-bearing/61804-2rs1 | 2026-09-24 | VERIFIED (page title) / GST UNVERIFIED |
| 61804 | SKF 61804-2RZ | SKF India e-Marketplace | 1,056 (title price) | not shown | 1 pc | – | 20×32×7 | https://www.emarketplace.in.skf.com/deep-groove-ball-bearing/61804-2rz | 2026-09-24 | VERIFIED (title) |
| 6805 | FBJ 6805-2RS | bearinghouse.in | 132.16 (ex 112) | 18% | 1 pc | In stock | 25×37×7 | https://bearinghouse.in/shop/fbj-6805-2rs-ball-bearing/ | 2026-09-24 | VERIFIED |
| 6805 | EVO 6805ZZCM | IndustryBuying | 152 (ex 129) | 18% | 1 pc, **MOQ 10** | In stock, ≤11 d | 25×37×7 | https://www.industrybuying.com/deep-groove-ball-bearings-evo-BEA.DEE.66136926 | 2026-09-24 | VERIFIED |
| 6805 | SKF 61805 (domestic, open) | bearinghouse.in | 260.78 (ex 221) | 18% | 1 pc | In stock | 25×37×7 open | https://bearinghouse.in/shop/skf-61805-6805-deep-groove-ball-bearing/ | 2026-09-24 | VERIFIED |
| 6805 | SKF 61805 (domestic) | IndustryBuying | 336 (ex 285) | 18% | 1 pc, MOQ 6 | In stock, ≤7 d | 25×37×7 | https://www.industrybuying.com/deep-groove-ball-bearings-skf-BEA.DEE.107402631 | 2026-09-24 | VERIFIED |
| 6805 | NBC 6805ZZ | bearinghouse.in | 300.90 (ex 255) | 18% | 1 pc | In stock | 25×37×7 ZZ | https://bearinghouse.in/shop/nbc-6805zz-ball-bearings/ | 2026-09-24 | VERIFIED |
| 6805 | NTN 6805JR | IndustryBuying | 353 (ex 299) | 18% | 1 pc, MOQ 2 | In stock, ≤8 d | 25×37×7 | https://www.industrybuying.com/deep-groove-ball-bearings-ntn-FAM165892 | 2026-09-24 | VERIFIED |
| 61805 | SKF 61805-2RS1 | bearinghouse.in | 1,588.28 (ex 1,346) | 18% | 1 pc | In stock | 25×37×7 | https://bearinghouse.in/shop/skf-61805-2rs1-6805-deep-groove-ball-bearing/ | 2026-09-24 | VERIFIED |
| 61805 | SKF 61805-2RS1 | SKF India e-Marketplace | 1,282 (title) | not shown | 1 pc | – | 25×37×7 | https://www.emarketplace.in.skf.com/deep-groove-ball-bearing/61805-2rs1 | 2026-09-24 | VERIFIED (title) |
| 6806 | FBJ 6806-2RS / 6806-ZZ | bearinghouse.in | 165.20 (ex 140) | 18% | 1 pc | In stock | 30×42×7 | https://bearinghouse.in/shop/fbj-6806-2rs-ball-bearing/ | 2026-09-24 | VERIFIED |
| 61806 | UBC 61806 / ZZ / 2RS | IndustryBuying | 100 (ex 85) | 18% | 1 pc, **MOQ 10** | In stock, ≤3 d | 30×42×7 generic | https://www.industrybuying.com/deep-groove-ball-bearings-ubc-BEA.DEE.68626093 | 2026-09-24 | VERIFIED |
| 61806 | CNA 61806 ZZ (Pack of 10) | Moglix | 2,313 /10 (ex 1,960) → **231/pc** | 18% | 10 pcs | Qty avail 100; ETA 1 Oct | 30×42×7 | https://www.moglix.com/cna-61806-zz-deep-groove-ball-bearing-42x30x7-mm-pack-of-10/mp/msnr50nw8p1251 | 2026-09-24 | VERIFIED |
| 6806 | NTN 6806JR | IndustryBuying | 459 (ex 389) | 18% | 1 pc | In stock, ≤8 d | 30×42×7 | https://www.industrybuying.com/deep-groove-ball-bearings-ntn-FAM165919 | 2026-09-24 | VERIFIED |
| 61806 | FAG 61806-HLC (imported) | IndustryBuying | 1,073 (ex 909) | 18% | 1 pc | In stock, ≤4 d | 30×42×7 | https://www.industrybuying.com/deep-groove-ball-bearings-fag-FAM156109 | 2026-09-24 | VERIFIED |
| 61806 | SKF 61806 (open) | bearinghouse.in | 1,416.00 (ex 1,200) | 18% | 1 pc | In stock | 30×42×7 | https://bearinghouse.in/shop/skf-6806-deep-groove-ball-bearing/ | 2026-09-24 | VERIFIED |
| 61806 | SKF 61806-2RS1 (imported) | bearinghouse.in | 1,949.36 (ex 1,652) | 18% | 1 pc | In stock | 30×42×7 | https://bearinghouse.in/shop/skf-61806-2rs1-6806-deep-groove-ball-bearing/ | 2026-09-24 | VERIFIED |
| 6807 | FBJ 6807-ZZ / 6807-2RS | bearinghouse.in | 184.08 / 192.34 (ex 156/163) | 18% | 1 pc | In stock | 35×47×7 | https://bearinghouse.in/shop/fbj-6807-2rs-ball-bearing/ | 2026-09-24 | VERIFIED |
| 6807 | EVO 6807LLUCM | IndustryBuying | 211 (ex 179) | 18% | 1 pc, MOQ 2 | In stock, ≤7 d | 35×47×7 sealed | https://www.industrybuying.com/deep-groove-ball-bearings-evo-BEA.DEE.26136943 | 2026-09-24 | VERIFIED |
| 61807 | UBC 61807 | IndustryBuying | 176 (ex 149) | 18% | 1 pc, MOQ 10 | In stock, ≤3 d | 35×47×7 | https://www.industrybuying.com/deep-groove-ball-bearings-ubc-BEA.DEE.98626137 | 2026-09-24 | VERIFIED |
| 61807 | CNA 61807 ZZ (Pack of 10) | Moglix | 2,582 /10 → **258/pc** (ex 2,188) | 18% | 10 pcs | Qty avail 100 | 35×47×7 | https://www.moglix.com/cna-61807-zz-single-row-deep-groove-ball-bearing-35x47x7-mm-pack-of-10/mp/msnr50nev0e251 | 2026-09-24 | VERIFIED |
| 61807 | ZKL 61807-2RS | IndustryBuying | 400 (ex 339) | 18% | 1 pc | In stock, ≤10 d | 35×47×7 (Czech/ZKL) | https://www.industrybuying.com/deep-groove-ball-bearings-zkl-BEA.DEE.325502172 | 2026-09-24 | VERIFIED |
| 6807 | KOYO 6807 | IndustryBuying | 530 (ex 449) | 18% | 1 pc | In stock, ≤30 d | 35×47×7 | https://www.industrybuying.com/deep-groove-ball-bearings-koyo-FAM116823 | 2026-09-24 | VERIFIED |
| 61807 | SKF 61807-2RS1 | bearinghouse.in | 2,256.16 (ex 1,912) | 18% | 1 pc | In stock | 35×47×7 | https://bearinghouse.in/shop/skf-61807-2rs1-6807-deep-groove-ball-bearing/ | 2026-09-24 | VERIFIED |
| 6808 | FBJ 6808-ZZ / 6808-2RS | bearinghouse.in | 247.80 / 276.12 (ex 210/234) | 18% | 1 pc | In stock | 40×52×7 | https://bearinghouse.in/shop/fbj-6808-2rs-ball-bearing/ | 2026-09-24 | VERIFIED |
| 61808 | UBC 61808 ZZ | IndustryBuying | 188 (ex 159) | 18% | 1 pc, MOQ 10 | In stock, ≤3 d | 40×52×7 | https://www.industrybuying.com/deep-groove-ball-bearings-ubc-BEA.DEE.98626160 | 2026-09-24 | VERIFIED |
| 6808 | NTN 6808JR | IndustryBuying | 589 (ex 499) | 18% | 1 pc | In stock, ≤8 d | 40×52×7 | https://www.industrybuying.com/deep-groove-ball-bearings-ntn-FAM165957 | 2026-09-24 | VERIFIED |
| 61808 | FAG 61808-2Z-HLC | IndustryBuying | 1,769 (ex 1,499) | 18% | 1 pc | In stock, ≤4 d | 40×52×7 | https://www.industrybuying.com/deep-groove-ball-bearings-fag-FAM156116 | 2026-09-24 | VERIFIED |
| 61808 | SKF 61808-2RS1 | bearinghouse.in | 3,348.84 (ex 2,838) | 18% | 1 pc | In stock | 40×52×7 | https://bearinghouse.in/shop/skf-61808-2rs1-6808-deep-groove-ball-bearing/ | 2026-09-24 | VERIFIED |
| 6810 | FBJ 6810-ZZ / 6810-2RS | bearinghouse.in | 401.20 / 469.64 (ex 340/398) | 18% | 1 pc | In stock | 50×65×7 | https://bearinghouse.in/shop/fbj-6810-2rs-ball-bearing/ | 2026-09-24 | VERIFIED |
| 61810 | UBC 61810 / ZZ / 2RS | IndustryBuying | 317 (ex 269) | 18% | 1 pc, MOQ 10 | In stock, ≤3 d | 50×65×7 | https://www.industrybuying.com/deep-groove-ball-bearings-ubc-BEA.DEE.38626207 | 2026-09-24 | VERIFIED |
| 61810 | ZKL 61810-2RS | IndustryBuying | 754 (ex 639) | 18% | 1 pc | In stock, ≤10 d | 50×65×7 | https://www.industrybuying.com/deep-groove-ball-bearings-zkl-BEA.DEE.925502253 | 2026-09-24 | VERIFIED |
| 6810 | NTN 6810JR | IndustryBuying | 837 (ex 709) | 18% | 1 pc | In stock, ≤8 d | 50×65×7 | https://www.industrybuying.com/deep-groove-ball-bearings-ntn-FAM165990 | 2026-09-24 | VERIFIED |
| 6810 | KOYO 6810ZZCM | IndustryBuying | 978 (ex 829) | 18% | 1 pc | In stock, ≤3 d | 50×65×7 | https://www.industrybuying.com/deep-groove-ball-bearings-koyo-FAM116826 | 2026-09-24 | VERIFIED |
| 61810 | SKF 61810-2RS1 | bearinghouse.in | 4,485.18 (ex 3,801) | 18% | 1 pc | In stock | 50×65×7 | https://bearinghouse.in/shop/skf-61810-2rs1-6810-deep-groove-ball-bearing/ | 2026-09-24 | VERIFIED |
| 6908 | FBJ 6908 / 6908-ZZ / 6908-2RS | bearinghouse.in | 238.36 / 266.68 / 276.12 | 18% | 1 pc | In stock | 40×62×12 | https://bearinghouse.in/shop/fbj-6908-2rs-ball-bearing/ | 2026-09-24 | VERIFIED |
| 61908 | UBC 61908 / ZZ / 2RS | IndustryBuying | 247 (ex 209) | 18% | 1 pc, MOQ 10 | In stock, ≤3 d | 40×62×12 | https://www.industrybuying.com/deep-groove-ball-bearings-ubc-BEA.DEE.28626703 | 2026-09-24 | VERIFIED |
| 6908 | KOYO 6908ZZC3 | IndustryBuying | 542 (ex 459) | 18% | 1 pc | In stock, ≤3 d | 40×62×12 | https://www.industrybuying.com/deep-groove-ball-bearings-koyo-FAM116859 | 2026-09-24 | VERIFIED |
| 6908 | NBC 6908ZZ | bearinghouse.in | 628.94 (ex 533) | 18% | 1 pc | In stock | 40×62×12 | https://bearinghouse.in/shop/nbc-6908zz-ball-bearings/ | 2026-09-24 | VERIFIED |
| 6908 | NTN 6908 | IndustryBuying | 825 (ex 699) | 18% | 1 pc | In stock, ≤5 d | 40×62×12 | https://www.industrybuying.com/deep-groove-ball-bearings-ntn-FAM163836 | 2026-09-24 | VERIFIED |
| 61908 | FAG 61908 / 61908-C3 | IndustryBuying | 2,359 (ex 1,999) | 18% | 1 pc | In stock, ≤4 d | 40×62×12 | https://www.industrybuying.com/deep-groove-ball-bearings-fag-FAM156117 | 2026-09-24 | VERIFIED |
| 61908 | SKF 61908-2RS1 / -2RZ | SKF India e-Marketplace | 4,235 (title) | not shown | 1 pc | – | 40×62×12 | https://www.emarketplace.in.skf.com/deep-groove-ball-bearing/61908-2rs1 | 2026-09-24 | VERIFIED (title) |
| 61908 | SKF 61908-2RS1 | bearinghouse.in | 5,272.24 (ex 4,468) | 18% | 1 pc | In stock | 40×62×12 | https://bearinghouse.in/shop/skf-61908-2rs1-6908-deep-groove-ball-bearing/ | 2026-09-24 | VERIFIED |
| 61904/5/6 | SKF 61904-2RS1 / 61905-2RS1 / 61906-2RS1 | SKF India e-Marketplace | 938 / 1,107 / 1,346 (title) | not shown | 1 pc | – | 20×37×9 / 25×42×9 / 30×47×9 | https://www.emarketplace.in.skf.com/deep-groove-ball-bearing/61906-2rs1 | 2026-09-24 | VERIFIED (title) |
| 61900–61902 | SKF 61900-2RS1 / 61901-2RS1 / 61902-2RS1 | SKF India e-Marketplace | 774 / 747 / 842 (title) | not shown | 1 pc | – | 10×22×6 / 12×24×6 / 15×28×7 | https://www.emarketplace.in.skf.com/deep-groove-ball-bearing/61901-2rs1 | 2026-09-24 | VERIFIED (title) |
| 6700 | NTN 6700 / NSK 6700 | IndustryBuying | 1,297 / 1,415 | 18% | 1 pc | In stock, ≤19 d | 10×15×3 | https://www.industrybuying.com/deep-groove-ball-bearings-ntn-BEA.DEE.638787477 | 2026-09-24 | VERIFIED (expensive; Japanese import) |
| 6704 | NSK 6704ZZ | IndustryBuying | 1,132 (ex 959) | 18% | 1 pc | In stock, ≤19 d | 20×27×4 | https://www.industrybuying.com/special-bearing-nsk-BEA.NSK.33961495 | 2026-09-24 | VERIFIED |

**Observations (bearings 1a):**
- Cheapest credible thin-section source = **bearinghouse.in FBJ** line (₹111–470 incl GST, 1-pc MOQ, in stock). FBJ is a Chinese commodity brand — fine for prototypes; check radial play before use in joint output stages.
- "Branded but cheap": **SKF domestic 61805 @ ₹261–336**, **NTN 6804JR–6810JR @ ₹353–837**, **KOYO 6807 @ ₹530**. Imported SKF 2RS1 thin-section = ₹1.3k–5.3k (4–10× FBJ).
- IB "UBC" generic 618xx is the lowest unit price (₹67–317) but **MOQ 10**.
- 6700-series (ultra-thin) only as Japanese imports at ₹1.1k–1.4k each on IB → avoid in design, or source via robu/AliExpress (not checked here).

### 1b. Standard small bearings (6000/6001/6002, 608, 625, 626, 688)

| Item | Brand/Model | Supplier | Price ₹ (incl GST) | GST | Qty | Stock | Key specs | URL | Date | Evidence |
|---|---|---|---|---|---|---|---|---|---|---|
| 6000 | FBJ 6000-2RS | bearinghouse.in | 40.12 (ex 34) | 18% | 1 | In stock | 10×26×8 | https://bearinghouse.in/shop/fbj-6000-2rs-ball-bearing/ | 2026-09-24 | VERIFIED |
| 6000 | NBC 6000RSS (2RS) | bearinghouse.in | 114.46 (ex 97) | 18% | 1 | In stock | 10×26×8 | https://bearinghouse.in/shop/nbc-6000rss-ball-bearings/ | 2026-09-24 | VERIFIED |
| 6000 | SKF 6000-2RS1 | bearinghouse.in | 238.36 (ex 202) | 18% | 1 | In stock | 10×26×8 | https://bearinghouse.in/shop/skf-6000-2rs1-deep-groove-ball-bearings/ | 2026-09-24 | VERIFIED |
| 6000 | SKF 6000-2RS1 | SKF India e-Marketplace | 174 (title) | not shown | 1 | – | 10×26×8 | https://www.emarketplace.in.skf.com/deep-groove-ball-bearing/6000-2rs1 | 2026-09-24 | VERIFIED (title) |
| 6000 | Quartz "6000 ZZ" | quartzcomponents.com | 23 | displayed | 1 | Available | 10×26×8 ZZ (unbranded) | https://quartzcomponents.com/products/6000-zz-metal-double-shielded-miniature-ball-bearings10mm-x-26mm-x-8mm-robotics | 2026-09-24 | VERIFIED (Shopify JSON) |
| 6001 | FBJ 6001-2RS | bearinghouse.in | 41.30 (ex 35) | 18% | 1 | In stock | 12×28×8 | https://bearinghouse.in/shop/fbj-6001-2rs-ball-bearing/ | 2026-09-24 | VERIFIED |
| 6001 | SKF 6001-2RS1 | SKF India e-Marketplace | 175 (title) | not shown | 1 | – | 12×28×8 | https://www.emarketplace.in.skf.com/deep-groove-ball-bearing/6001-2rs1 | 2026-09-24 | VERIFIED (title) |
| 6001 | MBL 6001 2RS | IndustryBuying | 39 (ex 33) | 18% | 1, MOQ 10 | In stock ≤4 d | 12×28×8 | https://www.industrybuying.com/deep-groove-ball-bearings-mbl-FAM247807 | 2026-09-24 | VERIFIED |
| 6002 | FBJ 6002-2RS | bearinghouse.in | 50.74 (ex 43) | 18% | 1 | In stock | 15×32×9 | https://bearinghouse.in/shop/fbj-6002-2rs-ball-bearing/ | 2026-09-24 | VERIFIED |
| 6002 | NBC 6002LLU (2RS) | bearinghouse.in | 148.68 (ex 126) | 18% | 1 | In stock | 15×32×9 | https://bearinghouse.in/shop/nbc-6002llu-ball-bearings/ | 2026-09-24 | VERIFIED |
| 6002 | SKF 6002-2RS1 | SKF India e-Marketplace | 189 (title) | not shown | 1 | – | 15×32×9 | https://www.emarketplace.in.skf.com/deep-groove-ball-bearing/6002-2rs1 | 2026-09-24 | VERIFIED (title) |
| 608 | FBJ 608-2RS | bearinghouse.in | 30.68 (ex 26) | 18% | 1 | In stock | 8×22×7 | https://bearinghouse.in/shop/fbj-608-2rs-ball-bearing/ | 2026-09-24 | VERIFIED |
| 608 | NBC 608ZZ | bearinghouse.in | 66.08 (ex 56) | 18% | 1 | In stock | 8×22×7 | https://bearinghouse.in/shop/nbc-608zz-ball-bearings/ | 2026-09-24 | VERIFIED |
| 608 | SKF 608-2RSH | SKF India e-Marketplace | 264 (title) | not shown | 1 | – | 8×22×7 | https://www.emarketplace.in.skf.com/deep-groove-ball-bearing/608-2rsh | 2026-09-24 | VERIFIED (title) |
| 608 | Quartz "608 2RS" | quartzcomponents.com | 24 | displayed | 1 | Available | 8×22×7 | https://quartzcomponents.com/products/608-2rs-rubber-sealed-ball-bearings-8-22-7-mm-double-rubber-sealed | 2026-09-24 | VERIFIED |
| 608 | Robocraze 608ZZ (Pack of 4) | robocraze.com | 135 /4 → 33.75/pc | incl | 4 | Available | 8×22×7 | https://robocraze.com/products/radial-ball-bearing-608zz-for-3d-printer-pack-of-4 | 2026-09-24 | VERIFIED |
| 625 | FBJ 625-ZZ / 625-2RS | bearinghouse.in | 44.84 / 53.10 | 18% | 1 | In stock | 5×16×5 | https://bearinghouse.in/shop/fbj-625-2rs-ball-bearing/ | 2026-09-24 | VERIFIED |
| 625 | Quartz "625 ZZ" | quartzcomponents.com | 20 | displayed | 1 | Available | 5×16×5 | https://quartzcomponents.com/products/606-zz-miniature-deep-groove-ball-bearing-6-17-6-mm-double-metal-shielded | 2026-09-24 | VERIFIED |
| 625 | Robocraze 625ZZ (Pack of 4) | robocraze.com | 69 /4 → 17.25/pc | incl | 4 | Available | 5×16×5 | https://robocraze.com/products/radial-ball-bearing-625zz-for-3d-printer-pack-of-4 | 2026-09-24 | VERIFIED |
| 625 | SKF 625-2Z | SKF India e-Marketplace | 253 (title) | not shown | 1 | – | 5×16×5 | https://www.emarketplace.in.skf.com/deep-groove-ball-bearing/625-2z | 2026-09-24 | VERIFIED (title) |
| 626 | FBJ 626-2RS / 626-ZZ | bearinghouse.in | 30.68 (ex 26) | 18% | 1 | In stock | 6×19×6 | https://bearinghouse.in/shop/fbj-626-2rs-ball-bearing/ | 2026-09-24 | VERIFIED |
| 626 | Robocraze 626ZZ | robocraze.com | 21 | incl | 1 | Available | 6×19×6 | https://robocraze.com/products/radial-ball-bearing-626zz-for-3d-printer | 2026-09-24 | VERIFIED |
| 626 | SKF 626-2RS | bearinghouse.in | 210.04 (ex 178) | 18% | 1 | In stock | 6×19×6 | https://bearinghouse.in/shop/skf-626-2rs-deep-groove-ball-bearing/ | 2026-09-24 | VERIFIED |
| 688 | FBJ 688-2RS | bearinghouse.in | 51.92 (ex 44) | 18% | 1 | In stock | 8×16×5 | https://bearinghouse.in/shop/fbj-688-2rs-ball-bearing/ | 2026-09-24 | VERIFIED |
| 688 | NBC 688ZZ | bearinghouse.in | 93.22 (ex 79) | 18% | 1 | In stock | 8×16×5 | https://bearinghouse.in/shop/nbc-688zz-ball-bearings/ | 2026-09-24 | VERIFIED |
| 688 | Quartz "688 ZZ" | quartzcomponents.com | 19 | displayed | 1 | Available | title says 8×22×7 but handle says 8×16×5 — **listing inconsistent, confirm** | https://quartzcomponents.com/products/688-zz-invento-8mm-rod-radial-ball-bearings-8x16x5mm-robotics-bearing | 2026-09-24 | VERIFIED (price) / spec UNVERIFIED |

**Small bearings for planetary carriers / idlers (6xx, MR)**

| Item | Brand/Model | Supplier | Price ₹ | GST | Qty | Stock | Key specs | URL | Date | Evidence |
|---|---|---|---|---|---|---|---|---|---|---|
| 623ZZ | Quartz "623 ZZ Bearings" | quartzcomponents.com | 25 | displayed | 1 | Available | 3×10×4 | https://quartzcomponents.com/products/623-zz-bearings-limiting-robotics-projects-3-x-10-x-4-mm-radial-bearing | 2026-09-24 | VERIFIED |
| 693ZZ | Quartz | quartzcomponents.com | 31 | displayed | 1 | Available | 3×8×4 | https://quartzcomponents.com/products/693zz-ball-bearings-miniature-carbon-steel-bearings-3mm-x-8mm-x-4-mm-deep-groove-bearing | 2026-09-24 | VERIFIED |
| 684ZZ / 604ZZ / 605ZZ | Quartz | quartzcomponents.com | 30 / 38 / 39 | displayed | 1 | Available | 4×9×4 / 4×12×4 / 5×14×5 | 684: https://quartzcomponents.com/products/608-zz-miniature-deep-groove-ball-bearing-8-22-7-mm-double-metal-shielded-copy-1 ; 604: https://quartzcomponents.com/products/12-4-4mm-ball-bearing-604-zz-stainless-steel-pack-of ; 605: https://quartzcomponents.com/products/m10r6-zz-miniature-deep-groove-ball-bearing-6-10-3-mm-double-metal-shielded-copy | 2026-09-24 | VERIFIED |
| MR105ZZ / MR106ZZ | Quartz | quartzcomponents.com | 60 / 60 | displayed | 1 | Available | 5×10×4 / 6×10×3 | MR105: https://quartzcomponents.com/products/625-zz-miniature-deep-groove-ball-bearing-5-16-5-mm-double-metal-shielded ; MR106: https://quartzcomponents.com/products/m10r5-zz-miniature-deep-groove-ball-bearing-5-10-4-mm-double-metal-shielded-copy | 2026-09-24 | VERIFIED (Quartz handles do not match titles) |
| 623-ZZ / 605-ZZ / 693ZZ | FBJ | bearinghouse.in | 48.38 / 48.38 / 41.30 (ex 41/41/35) | 18% | 1 | In stock | – | https://bearinghouse.in/shop/fbj-623-zz-ball-bearing/ | 2026-09-24 | VERIFIED |
| 623ZZ | NBC / SKF 623-2Z | bearinghouse.in | 93.22 / 247.80 | 18% | 1 | In stock | – | https://bearinghouse.in/shop/skf-623-2z-zz-deep-groove-ball-bearing/ | 2026-09-24 | VERIFIED |
| F688ZZ | Robokits | robokits.co.in | 26 | not stated* | 1 | In stock | 8×16×5 flanged | https://robokits.co.in/3d-printer/accessories/f688zz-flanged-shielded-deep-groove-ball-bearing | 2026-09-24 | VERIFIED |

(*Robokits GST: see note under §2a.)

### 1c. Angular-contact (7000 series) — for preloaded pairs (e.g. hip-yaw, wrist)

| Item | Brand/Model | Supplier | Price ₹ (incl GST) | GST | Qty | Stock | Key specs | URL | Date | Evidence |
|---|---|---|---|---|---|---|---|---|---|---|
| 7001 | KOYO 7001 | IndustryBuying | 601 (ex 509) | 18% | 1 | In stock ≤3 d | 12×28×8, single row | https://www.industrybuying.com/angular-contact-ball-bearings-koyo-BEA.ANG.14120958 | 2026-09-24 | VERIFIED |
| 7001 | NTN 7001 | IndustryBuying | 612 (ex 519) | 18% | 1 | In stock ≤8 d | 12×28×8 | https://www.industrybuying.com/angular-contact-ball-bearings-ntn-PO.BE.AN.181059 | 2026-09-24 | VERIFIED |
| 7001 | NTN 7001 (Pack of 5) | Moglix | 2,677 /5 → 535/pc (ex 2,269) | 18% | 5 | MOQ 1 pack; qty-available field = 1 | 12×28×8, C 5.05 kN | https://www.moglix.com/ntn-12x28x8mm-single-angular-contact-ball-bearing-7001-pack-of-5/mp/msn4k6zjywp8kq | 2026-09-24 | VERIFIED |
| 7002 | KOYO 7002 | IndustryBuying | 695 (ex 589) | 18% | 1 | In stock ≤4 d | 15×32×9 | https://www.industrybuying.com/angular-contact-ball-bearings-koyo-BEA.ANG.14120965 | 2026-09-24 | VERIFIED |
| 7002 | NTN 7002 | IndustryBuying | 707 (ex 599) | 18% | 1 | In stock ≤8 d | 15×32×9 | https://www.industrybuying.com/angular-contact-ball-bearings-ntn-FAM168870 | 2026-09-24 | VERIFIED |
| 7000 | NSK 7000A | IndustryBuying | 1,769 (ex 1,499) | 18% | 1 | In stock ≤19 d | 10×26×8 | https://www.industrybuying.com/angular-contact-ball-bearings-nsk-BEA.ANG.238731051 | 2026-09-24 | VERIFIED |
| 7200 | SKF 7200 BEP | bearinghouse.in | 1,686.22 (ex 1,429) | 18% | 1 | In stock | 10×30×9 (per designation) | https://bearinghouse.in/shop/skf-7200-bep-angular-contact-ball-bearing/ | 2026-09-24 | VERIFIED |
| 7201 / 7202 | SKF 7201 BEP / 7202 BEP | SKF India e-Marketplace | 1,413 / 1,396 (title price) | not shown | 1 | – | 12×32×10 / 15×35×11 (per designation) | https://www.emarketplace.in.skf.com/angular-contact-ball-bearing/7201-bep | 2026-09-24 | VERIFIED (title) |

Note: No cheap generic 7000-series seen at bearinghouse/IB; KOYO/NTN 7001–7002 at ₹600–700 are the best value found. For thin preloaded pairs consider 2× 6800-series back-to-back with printed spacers instead (design option).

### 1d. Crossed-roller bearings (RU / RB / CRBH / CRBC)

| Item | Brand/Model | Supplier | Price ₹ | GST | Qty | Stock | Key specs | URL | Date | Evidence |
|---|---|---|---|---|---|---|---|---|---|---|
| CRBHV3510 | IKO CRBHV3510AC1 | IndustryBuying | 11,799 (ex 9,999) | 18% | 1 | "In stock", ships ≤19 d | C = 7,900 N (listing); 35×60×10 per IKO designation (not on listing) | https://www.industrybuying.com/special-bearing-iko-BEA.SPE.939191295 | 2026-09-24 | VERIFIED |
| CRB4010 | IKO CRB4010C1 | IndustryBuying | 15,339 (ex 12,999) | 18% | 1 | ≤19 d | C = 5,980 N (listing); 40×65×10 per designation (not on listing) | https://www.industrybuying.com/special-bearing-iko-BEA.SPE.939192083 | 2026-09-24 | VERIFIED |
| CRB5013 | IKO CRB5013C1 | IndustryBuying | 15,339 (ex 12,999) | 18% | 1 | ≤19 d | C = 14,200 N (listing); 50×80×13 per designation (not on listing) | https://www.industrybuying.com/special-bearing-iko-BEA.SPE.739192138 | 2026-09-24 | VERIFIED |
| RB3510 | "THK RB3510 UU" | IndiaMART seller (Ahmedabad, listing) | 4,200 /pc (listing) | ? | 1 | ? | 35×60×10 per THK designation | https://dir.indiamart.com/impcat/crossed-roller-bearings.html | 2026-09-24 | UNVERIFIED (lead; authenticity unknown) |
| RB/CRB 20 mm bore | "Crossed Roller Bearings" RB/CRB, 20 bore, 36 OD | IndiaMART — Vaibhav Bearing Centre, Mumbai | 4,000 /pc (listing) | ? | 1 | ? | 20×36 (≈RB2008) | https://dir.indiamart.com/impcat/crossed-roller-bearings.html | 2026-09-24 | UNVERIFIED |
| RU42/RU66/RU85 | "THK Cross Roller Ring RU" | IndiaMART — Mechatronix Pvt Ltd, Mumbai | 22,500 /pc (listing) | ? | 1 | ? | RU42 = 20×70×12 | https://dir.indiamart.com/impcat/crossed-roller-bearings.html | 2026-09-24 | UNVERIFIED |
| RB2008 | RB2008UUCCOP5 | IndiaMART — JK Linear Motion, Dombivli | 1,111 (placeholder; seller says "ask price") | ? | 1 | ? | 20×36×8 | https://dir.indiamart.com/impcat/crossed-roller-bearings.html | 2026-09-24 | UNVERIFIED |

**Crossed-roller takeaway:** genuine IKO/THK in India = ₹11.8k–22.5k each → not viable for a ~12–14-joint low-cost build. Options: (a) import Chinese RU42/CRBH-class (not priced here — out of scope), (b) replace with **pairs of 68xx/69xx thin-section bearings** (₹110–470 each from bearinghouse FBJ) spaced apart in a printed/aluminium housing, or (c) **4-point contact wire-race / printed-race** designs. Recommend (b) for JX1 v1.

### 1e. Thrust & needle bearings

| Item | Brand/Model | Supplier | Price ₹ (incl GST) | GST | Qty | Stock | Key specs | URL | Date | Evidence |
|---|---|---|---|---|---|---|---|---|---|---|
| 51100 | FBJ 51100 | bearinghouse.in | 73.16 (ex 62) | 18% | 1 | In stock | 10×24×9 thrust ball | https://bearinghouse.in/shop/fbj-51100-thrust-ball-bearing/ | 2026-09-24 | VERIFIED |
| 51100 | UBC 51100 | IndustryBuying | 68 (ex 58) | 18% | 1, MOQ 10 | In stock ≤3 d | 10×24×9 | https://www.industrybuying.com/thrust-roller-bearings-ubc-BEA.THR.98612717 | 2026-09-24 | VERIFIED |
| 51101 | FBJ 51101 | bearinghouse.in | 77.88 (ex 66) | 18% | 1 | In stock | 12×26×9 | https://bearinghouse.in/shop/fbj-51101-thrust-ball-bearing/ | 2026-09-24 | VERIFIED |
| 51101 | NBC 51101 | bearinghouse.in | 151.04 (ex 128) | 18% | 1 | In stock | 12×26×9 | https://bearinghouse.in/shop/nbc-51101-ball-bearings/ | 2026-09-24 | VERIFIED |
| 51104 | N2K 51104 | bearinghouse.in | 34.22 (ex 29) | 18% | 1 | In stock | 20×35×10 | https://bearinghouse.in/shop/n2k-51104-thrust-ball-bearing/ | 2026-09-24 | VERIFIED |
| 51104 | NBC 51104 | bearinghouse.in | 168.74 (ex 143) | 18% | 1 | In stock | 20×35×10 | https://bearinghouse.in/shop/nbc-51104-ball-bearings/ | 2026-09-24 | VERIFIED |
| 51104 | NBC 51104 | IndustryBuying | 152 (ex 129) | 18% | 1, MOQ 5 | In stock ≤4 d | 20×35×10 | https://www.industrybuying.com/thrust-roller-bearings-nbc-PO.BE.DE.455405 | 2026-09-24 | VERIFIED |
| 51106 | N2K 51106 | bearinghouse.in | 62.54 (ex 53) | 18% | 1 | In stock | 30×47×11 | https://bearinghouse.in/shop/n2k-51106-thrust-ball-bearing/ | 2026-09-24 | VERIFIED |
| 51106 | NBC 51106 | bearinghouse.in | 234.82 (ex 199) | 18% | 1 | In stock | 30×47×11 | https://bearinghouse.in/shop/nbc-51106-ball-bearings/ | 2026-09-24 | VERIFIED |
| AXK3047 | KHK AXK 3047 needle thrust | bearinghouse.in | 118.00 (ex 100) | 18% | 1 | In stock | 30×47 per designation (check whether AS washers are included) | https://bearinghouse.in/shop/khk-axk-3047-needle-thrust-bearings/ | 2026-09-24 | VERIFIED |
| AXK3047 | INA AXK3047-A/0-10 | IndustryBuying | 1,179 (ex 999) | 18% | 1 | ≤120 d | 30×47 | https://www.industrybuying.com/spherical-roller-bearings-ina-BEA.SPH.434946234 | 2026-09-24 | VERIFIED (long lead) |
| AXK1024 | INA AXK1024-A/0-10 | IndustryBuying | 931 (ex 789) | 18% | 1 | ≤120 d | 10×24 | https://www.industrybuying.com/spherical-roller-bearings-ina-BEA.SPH.234946186 | 2026-09-24 | VERIFIED (long lead) |
| HK0810 | N2K HK0810 | bearinghouse.in | 35.40 (ex 30) | 18% | 1 | In stock | 8×12×10 drawn cup | https://bearinghouse.in/shop/n2k-hk0810-needle-roller-bearing/ | 2026-09-24 | VERIFIED |
| HK0810 | NTN HK0810C | IndustryBuying | 84 (ex 71) | 18% | 1, MOQ 10 | In stock ≤8 d | 8×12×10 | https://www.industrybuying.com/needle-roller-bearings-ntn-PO.BE.NE.185996 | 2026-09-24 | VERIFIED |
| HK1012 | N2K HK1012 | bearinghouse.in | 41.30 (ex 35) | 18% | 1 | In stock | 10×14×12 | https://bearinghouse.in/shop/n2k-hk1012-needle-roller-bearing/ | 2026-09-24 | VERIFIED |
| HK1012 | INA HK1012 | bearinghouse.in | 177.00 (ex 150) | 18% | 1 | In stock | 10×14×12 | https://bearinghouse.in/shop/ina-hk1012-needle-roller-bearing/ | 2026-09-24 | VERIFIED |
| HK1012 | NTN HK1012 | IndustryBuying | 103 (ex 87) | 18% | 1, MOQ 5 | ≤30 d | 10×14×12 | https://www.industrybuying.com/needle-roller-bearings-ntn-FAM167547 | 2026-09-24 | VERIFIED |

(AXK2035 was not found on IB/bearinghouse under that exact number on 2026-09-24.)

### 1f. Flanged miniature bearings

| Item | Brand/Model | Supplier | Price ₹ | GST | Qty | Stock | Key specs | URL | Date | Evidence |
|---|---|---|---|---|---|---|---|---|---|---|
| F688ZZ | Quartz F688ZZ | quartzcomponents.com | 36 | displayed | 1 | Available | 8×16×5 flanged | https://quartzcomponents.com/products/f688zz-flanged-stee-ball-bearing | 2026-09-24 | VERIFIED |
| F608ZZ | FBJ F-608-ZZ | bearinghouse.in | 106.20 (ex 90) | 18% | 1 | In stock | 8×22×7 flanged | https://bearinghouse.in/shop/fbj-f-608-zz-ball-bearing/ | 2026-09-24 | VERIFIED |
| F625ZZ | NSK F625ZZ | IndustryBuying | 483 (ex 409) | 18% | 1 | ≤19 d | 5×16×5 flanged | https://www.industrybuying.com/flange-bearings-nsk-BEA.NSK.83961247 | 2026-09-24 | VERIFIED |
| MF105ZZ | Robocraze MF105ZZ | robocraze.com | 42 | incl | 1 | Available | 5×10×4 flanged | https://robocraze.com/products/mf105zz-flanged-shielded-bearing | 2026-09-24 | VERIFIED |
| F604ZZ | Robocraze F604ZZ | robocraze.com | 40 | incl | 1 | Available | 4×12×4 flanged | https://robocraze.com/products/f604zz-flanged-shielded-ball-bearing | 2026-09-24 | VERIFIED |

---
## 2. FASTENERS

Per-piece cost is shown as ESTIMATED (= pack price ÷ pack qty).

### 2a. Socket-head cap screws (SHCS), button/countersunk heads

| Item | Brand/Model | Supplier | Price ₹ (incl GST) | GST | Qty | Stock / lead | Key specs | URL | Date | Evidence |
|---|---|---|---|---|---|---|---|---|---|---|
| M3×8 SHCS | Unbrako 5000731 | IndustryBuying | 211 (ex 179) → ₹2.11/pc | 18% | Pack 100, MOQ 1 | In stock, ships ≤30 d | ISO 4762 / DIN 912, **A2-70, AISI 304** (PDP spec) | https://www.industrybuying.com/socket-head-cap-screw-unbrako-FA.SC.SO4.208127 | 2026-09-24 | VERIFIED (PDP JSON-LD + spec) |
| M3×6/10/12/16/20 SHCS | Unbrako 5000730/32/33/34/35 | IndustryBuying | 223 / 223 / 223 / 247 / 270 per 100 | 18% | Pack 100 | ≤30 d | ISO 4762; material not stated on these PDPs (sister SKU 5000731 = A2-70) | https://www.industrybuying.com/socket-head-cap-screw-unbrako-FA.SC.SO4.208129 | 2026-09-24 | VERIFIED (price) / material UNVERIFIED |
| M3×8 SHCS | Unbrako 5000947 | IndustryBuying | 258 (ex 219) | 18% | Pack 100 | ≤30 d | ISO 4762 (grade not stated) | https://www.industrybuying.com/socket-head-cap-screw-unbrako-FA.SC.SO4.208403 | 2026-09-24 | VERIFIED |
| M4×8/10/12/16 SHCS | Unbrako 5000739/40/41/42 | IndustryBuying | 247 / 235 / 235 / 270 per 100 (≈₹2.35/pc) | 18% | Pack 100 | ≤30 d | ISO 4762 | https://www.industrybuying.com/socket-head-cap-screw-unbrako-FA.SC.SO4.208137 | 2026-09-24 | VERIFIED |
| M5×10/12/16/20/25 SHCS | Unbrako 5000749/50/51/52/53 | IndustryBuying | 294 / 317 / 353 / 388 / 435 per 100 | 18% | Pack 100 | ≤30 d | ISO 4762 | https://www.industrybuying.com/socket-head-cap-screw-unbrako-FA.SC.SO4.208146 | 2026-09-24 | VERIFIED |
| M6×10/12/16/20/25 SHCS | Unbrako 5000762/63/64/65/66 | IndustryBuying | 388 / 400 / 435 / 471 / 530 per 100 | 18% | Pack 100 (M6×10/12 MOQ 2 packs) | ≤30 d | ISO 4762 | https://www.industrybuying.com/socket-head-cap-screw-unbrako-FA.SC.SO4.208159 | 2026-09-24 | VERIFIED |
| M2.5×10 SHCS | Unbrako 104164 | IndustryBuying | 3,303 (ex 2,799) per 500 | 18% | Pack 500, **MOQ 3 packs** | ≤30 d | – | https://www.industrybuying.com/socket-head-cap-screw-unbrako-FAM257494 | 2026-09-24 | VERIFIED (MOQ makes it ₹9.9k) |
| M3×16 SHCS **12.9** | Caparo (full thread) | IndustryBuying | 896 (ex 759) per 200 → ₹4.48/pc | 18% | Pack 200 | ≤30 d | Grade 12.9 alloy | https://www.industrybuying.com/allen-cap-screw-caparo-FAM170624 | 2026-09-24 | VERIFIED |
| M3×18 SHCS **12.9** | TVS | Moglix | 5,747 (ex 4,864) per 1000 → ₹5.75/pc | 18% | Pack 1000, MOQ 2 | qty-available field = 0 → confirm | 12.9 | https://www.moglix.com/tvs-m3x18mm-socket-head-cap-screw-grade-129-pack-of-1000/mp/msnl5glgxdpyk4 | 2026-09-24 | VERIFIED listing / stock UNVERIFIED |
| M6×10 SHCS **12.9** | TVS | Moglix | 2,322 (ex 1,973) per 500 → ₹4.64/pc | 18% | Pack 500, MOQ 2 | qty 0 → confirm | 12.9 | https://www.moglix.com/tvs-m6x10mm-socket-head-cap-screw-grade-129-pack-of-500/mp/msnpkep782ld9g | 2026-09-24 | VERIFIED listing / stock UNVERIFIED |
| M4×10 SHCS | Generic carbon steel FACSM410 | IndustryBuying | 84 (ex 71) per 100 | 18% | Pack 100, MOQ 2 | In stock | carbon steel, grade n/s | https://www.industrybuying.com/allen-cap-screw-generic-FAM113225 | 2026-09-24 | VERIFIED |
| M3×8 / M4×10 / M5×10 SHCS | Zhongfa "Alloy Steel Black-Oxide Socket Head" | thinkrobotics.com | 64.99 / 99.99 / 169.99 per 10 | displayed | Pack 10 | Available | alloy steel black oxide | https://thinkrobotics.com/products/alloy-steel-black-oxide-socket-head-screws-pack-of-10 | 2026-09-24 | VERIFIED (Shopify variant JSON) |
| M3×8 SHCS | Quartz SS202 | quartzcomponents.com | 35 per 10 | displayed | Pack 10 | Available | SS202, head Ø5.3 | https://quartzcomponents.com/products/m3-x-8mm-hex-allen-socket-head-screwpack-of-10 | 2026-09-24 | VERIFIED |
| M3×8 SHCS | Robokits SS304 | robokits.co.in | 13.00 /pc (MOQ 15) | not stated* | per pc | In stock | SS304 | https://robokits.co.in/robot-parts/nut-bolts-standoffs/allen-cap-socket-head-bolts/m3-x-8-mm-socket-head-cap-stainless-steel-304-bolt-moq-15-pcs | 2026-09-24 | VERIFIED |
| M3×10 button head | Rpi Ind | IndustryBuying | 424 (ex 359) per 100 | 18% | Pack 100 | ≤6 d | button head socket | https://www.industrybuying.com/allen-cap-screw-rpi-ind-FAM180456 | 2026-09-24 | VERIFIED |
| M3×8 button head A2 | TR Fastenings | IndustryBuying | 671 (ex 569) per 50 | 18% | Pack 50 | ≤20 d | A2 stainless, button head hex socket | https://www.industrybuying.com/self-tapping-screw-tr-fastenings-HAR.SEL.833449943 | 2026-09-24 | VERIFIED |
| M4×25 button head 10.9 | Zhongfa | thinkrobotics.com | 109.99 per 10 | displayed | Pack 10 | Available (many other sizes OOS) | class 10.9 | https://thinkrobotics.com/products/metric-alloy-steel-button-head-hex-drive-screws-class-10-9-alloy-steel | 2026-09-24 | VERIFIED |
| M4×8 countersunk | Rpi Ind CSK socket | IndustryBuying | 353 (ex 299) per 50 | 18% | Pack 50 | ≤4 d | countersunk hex socket (bright) | https://www.industrybuying.com/allen-cap-screw-rpi-ind-FAM180466 | 2026-09-24 | VERIFIED |
| M3×12 countersunk A2 | TR Fastenings | IndustryBuying | 695 (ex 589) per 50 | 18% | Pack 50 | ≤20 d | A2 CSK hex socket | https://www.industrybuying.com/special-screw-tr-fastenings-HAR.SPE.930902195 | 2026-09-24 | VERIFIED |

\*Robokits product pages show "GST Input Tax Credit @18 % of ₹X" where X = 18 % × displayed price (e.g. ₹315 item → ₹56.7), which suggests displayed prices may be **ex-GST**; confirm at checkout.

### 2b. Nuts, washers

| Item | Brand/Model | Supplier | Price ₹ (incl GST) | GST | Qty | Stock | Key specs | URL | Date | Evidence |
|---|---|---|---|---|---|---|---|---|---|---|
| M4 nyloc | TR Fastenings N5ST-Z | IndustryBuying | 188 (ex 159) per 100 | 18% | Pack 100 | ≤20 d | steel, zinc plated | https://www.industrybuying.com/lock-nut-tr-fastenings-HAR.LOC.830907894 | 2026-09-24 | VERIFIED |
| M3/M4/M5 nyloc A4 | TR Fastenings | IndustryBuying | 494 / 589 / 565 per 50 | 18% | Pack 50 | ≤20 d | stainless A4 | https://www.industrybuying.com/lock-nut-tr-fastenings-HAR.LOC.730908003 | 2026-09-24 | VERIFIED |
| M3 / M4 nyloc SS | Unbrako 5010922 / 5010923 (ISO 10511) | IndustryBuying | 211 / 188 per 100 | 18% | Pack 100, **MOQ 100 packs** (PDP price = ₹21,100 / ₹18,800) | ≤30 d | stainless | https://www.industrybuying.com/nyloc-nut-unbrako-FAS.NYL.72502243 | 2026-09-24 | VERIFIED — not practical (MOQ) |
| M3 nyloc SS304 | Robokits | robokits.co.in | 2.00 /pc, MOQ 25 | not stated* | per pc | In stock | SS304 | https://robokits.co.in/robot-parts/nut-bolts-standoffs/nuts/m3-nyloc-nuts-304-stainless-steel-moq-25-pcs | 2026-09-24 | VERIFIED |
| M3 / M4 / M5 hex nut A2 | Unbrako 5001319 / 5001320 / 5001321 | IndustryBuying | 66 / 81 / 97 per 100 | 18% | Pack 100, MOQ 4 / 3 / 2 packs | ≤30 d | SS304 A2 | https://www.industrybuying.com/hex-nut-unbrako-FA.NU.HE0.593413 | 2026-09-24 | VERIFIED |
| M3 hex nut SS304 | Robokits | robokits.co.in | 1.00 /pc, MOQ 50 | not stated* | per pc | In stock (M4: OOS) | SS304 | https://robokits.co.in/robot-parts/nut-bolts-standoffs/nuts/m3-nuts-304-stainless-steel-moq-50-pcs | 2026-09-24 | VERIFIED |
| M5 flange nut (serrated) | TR Fastenings SFST-Z | IndustryBuying | 294 (ex 249) per 100 | 18% | Pack 100 | ≤20 d | steel BZP | https://www.industrybuying.com/nuts-tr-fastenings-HAN.NUT.333455048 | 2026-09-24 | VERIFIED |
| M5 flange nut SS304 | Astro (Robokits) | robokits.co.in | 11.50 /pc, MOQ 10 | not stated* | per pc | In stock | SS304 | https://robokits.co.in/mechanical-parts/aluminium-profile-accessories/astro-m5-flange-nuts-304-stainless-steel-moq-10-pcs | 2026-09-24 | VERIFIED |
| M3 spring washer | Unbrako 5001420 | IndustryBuying | 85 (ex 72) per 100 | 18% | Pack 100 | ≤30 d | spring (flat section) | https://www.industrybuying.com/plain-washer-unbrako-FA.WA6.335313 | 2026-09-24 | VERIFIED |
| M3 flat washer | Tanish SS202 1 mm | IndustryBuying | 78 (ex 66) per 100 | 18% | Pack 100, MOQ 3 | ≤30 d | SS202 | https://www.industrybuying.com/plain-washer-tanish-enterprises-FAM285751 | 2026-09-24 | VERIFIED |
| M3 / M4 / M5 flat washer SS304 | Robokits | robokits.co.in | 2.40 / 3.20 / 4.80 per pc, MOQ 50 | not stated* | per pc | In stock | SS304 | https://robokits.co.in/robot-parts/nut-bolts-standoffs/washers/m3-flat-washer-304-stainless-steel-moq-50-pcs | 2026-09-24 | VERIFIED |
| M3 / M4 flat washer | Quartz "Flat SS Washer" | quartzcomponents.com | 2 /pc | displayed | 1 | Available | SS | https://quartzcomponents.com/products/m3-zinc-plated-steel-washer | 2026-09-24 | VERIFIED |

### 2c. Pins, set screws, circlips, shoulder bolts

| Item | Brand/Model | Supplier | Price ₹ (incl GST) | GST | Qty | Stock / lead | Key specs | URL | Date | Evidence |
|---|---|---|---|---|---|---|---|---|---|---|
| Dowel 3×14 / 3×20 | CE solid dowel pin | IndustryBuying | 471 / 589 per 100 | 18% | Pack 100 | ≤3–4 d | solid steel dowel (tolerance not stated) | https://www.industrybuying.com/dowel-pin-ce-FAM239553 | 2026-09-24 | VERIFIED |
| Dowel 4×14 / 4×20 | CE | IndustryBuying | 518 / 624 per 100 | 18% | Pack 100 | ≤4 d | – | https://www.industrybuying.com/dowel-pin-ce-FAM239546 | 2026-09-24 | VERIFIED |
| Dowel 5×14 / 5×20 | CE | IndustryBuying | 565 / 719 per 100 | 18% | Pack 100 | ≤3–4 d | – | https://www.industrybuying.com/dowel-pin-ce-FAM239553 | 2026-09-24 | VERIFIED |
| Dowel 3×40 hardened | Unbrako 402124 | IndustryBuying | 601 per 40 | 18% | Pack 40, **MOQ 10 packs** | ≤30 d | high-grade alloy (hardened) | https://www.industrybuying.com/dowel-pin-unbrako-FAM257317 | 2026-09-24 | VERIFIED (MOQ ₹6k) |
| Dowel 3×10 / 4×10 / 5×10 | Zhongfa alloy steel | thinkrobotics.com | 149.99 / 179.99 / 239.99 per 10 | displayed | Pack 10 | Available | alloy steel | https://thinkrobotics.com/products/dowel-pins-assembly-pins | 2026-09-24 | VERIFIED |
| Grub M3×3 | Immech (bright) | IndustryBuying | 100 (ex 85) per 10 | 18% | Pack 10, MOQ 5 | ≤5 d | hex socket set screw | https://www.industrybuying.com/grub-screw-immech-FAM203248 | 2026-09-24 | VERIFIED |
| Grub M4×4 | Rpi Shop | IndustryBuying | 188 (ex 159) per 25 | 18% | Pack 25, MOQ 2 | ≤4 d | – | https://www.industrybuying.com/grub-screw-rpi-shop-FAM205622 | 2026-09-24 | VERIFIED |
| Set screw M3×10 cup | TVS knurled cup point | Moglix | 303 (ex 255) per 100 | 18% | Pack 100, MOQ 2 | qty 0 → confirm | TVS | https://www.moglix.com/tvs-10-mm-metric-series-m3-knurled-cup-point-socket-set-screw-pack-of-100/mp/msn2km1dz43x9v | 2026-09-24 | VERIFIED listing |
| Set screw M3×6 / M4×5 cup | Zhongfa | thinkrobotics.com | 34.99 / 29.99 per 5 | displayed | Pack 5 | Available | alloy steel | https://thinkrobotics.com/products/metric-alloy-steel-cup-point-set-screws | 2026-09-24 | VERIFIED |
| E-clip 4 mm | Qualfast | IndustryBuying | 129 (ex 109) per 100 | 18% | Pack 100, MOQ 3 | ≤2 d | carbon steel (standard not stated) | https://www.industrybuying.com/e-clips-qualfast-FAS.ECL.66551590 | 2026-09-24 | VERIFIED |
| E-clip 5 mm | Qualfast | IndustryBuying | 164 (ex 139) per 100 | 18% | Pack 100, MOQ 2 | ≤90 d | – | https://www.industrybuying.com/e-clips-qualfast-FAS.ECL.76551601 | 2026-09-24 | VERIFIED |
| Internal circlip 8/10/12 mm | Qualfast | IndustryBuying | 105 / 140 / 140 per 50 | 18% | Pack 50 (MOQ 5/1/2) | ≤90 d (10 mm: n/s) | internal circlip (standard not stated) | https://www.industrybuying.com/internal-circlip-qualfast-FAS.CIR.96551431 | 2026-09-24 | VERIFIED |
| External circlip 18 mm | Qualfast | IndustryBuying | 152 (ex 129) per 25 | 18% | Pack 25, MOQ 2 | ≤2 d | external circlip (standard not stated) | https://www.industrybuying.com/external-circlip-qualfast-FAS.CIR.36551363 | 2026-09-24 | VERIFIED |
| Circlip kit 890 pcs | RS PRO 523165 | IndustryBuying | 11,091 | 18% | kit | ≤20 d | E/int/ext 1.7–12 mm | https://www.industrybuying.com/circlip-pliers-rs-pro-HAN.CIR.520659764 | 2026-09-24 | VERIFIED (poor value) |
| Shoulder bolts | – | IB / Moglix / Shopify stores | **not found** (only Makita spare-part shoulder bolts) | – | – | – | – | – | 2026-09-24 | NOT FOUND → use dowel + SHCS or turned bushings |

### 2d. Threaded inserts for printed parts, kits

| Item | Brand/Model | Supplier | Price ₹ | GST | Qty | Stock | Key specs | URL | Date | Evidence |
|---|---|---|---|---|---|---|---|---|---|---|
| M3 heat-set L8 | Quartz "M3x8x4.2mm Brass Heat Set" | quartzcomponents.com | **33 per 10** | displayed | Pack 10 | Available | knurled brass; title = M3 × 8 L × 4.2 OD (listing text inconsistent — confirm dims) | https://quartzcomponents.com/products/m3-x-8mm-brass-heat-set-threaded-round-insert-nut-10-pcs | 2026-09-24 | VERIFIED (price) |
| M3 heat-set L4 / L6 / L10 / L12 | Quartz | quartzcomponents.com | 43 / 58 / 70 / 65 per 10 | displayed | Pack 10 | Available | OD 4.2 | https://quartzcomponents.com/products/m3-x-4mm-brass-heat-set-threaded-round-insert-nut-10-pcs | 2026-09-24 | VERIFIED |
| M3 heat-set L15 OD5 | Quartz | quartzcomponents.com | 62 per 10 | displayed | Pack 10 | Available | – | https://quartzcomponents.com/products/m3-x-15mm-brass-heat-set-threaded-round-insert-nut-10-pcs | 2026-09-24 | VERIFIED |
| M2.5 / M3 / M4 / M5 heat-set | ThinkRobotics MEC8005 | thinkrobotics.com | 59.99 / 64.99 (**M3 OOS**) / 79.99 / 99.99 per 10 | displayed | Pack 10 | M2.5, M4, M5 available | knurled brass: M3×4.5, M4×5, M5×6 | https://thinkrobotics.com/products/brass-heat-set-inserts-for-plastic | 2026-09-24 | VERIFIED |
| M2×5 heat-set | Robokits | robokits.co.in | 2.52 /pc, MOQ 25 | not stated* | per pc | listed | brass | https://robokits.co.in/robot-parts/nut-bolts-standoffs/nuts/m2-x-5-mm-brass-heat-threaded-round-insert-nut-moq-25-pcs | 2026-09-24 | VERIFIED |
| M3 industrial insert | SI IUB-M3-1 (brass, OD 4.37) | IndustryBuying | 109 (ex 92) **each** | 18% | 1, MOQ 5 | ≤45 d | brass threaded insert (install type not stated) | https://www.industrybuying.com/mounting-accessories-si-IND.MOU.635734646 | 2026-09-24 | VERIFIED (≈30× Quartz price) |
| Heat-insert tip set M2–M6 | amiciTools | IndustryBuying | 778 (ex 659) | 18% | set | ≤5 d | soldering-iron tips | https://www.industrybuying.com/soldering-kits-amicitools-WEL.SOL.640810027 | 2026-09-24 | VERIFIED |
| M4 Phillips assortment 180 pcs | Quartz KIT-QC4841 | quartzcomponents.com | 298 | displayed | 180 pcs | Available | M4 6–25 mm pan head | https://quartzcomponents.com/products/bolts-and-nuts-kit-m3-copy | 2026-09-24 | VERIFIED |

**Fastener takeaways:** For bulk socket-head screws use **Unbrako packs of 100 on IB (₹2.1–5.3/pc; 30-day lead)** — the one PDP checked (M3×8, 5000731) is **A2-70 stainless**, not 12.9. For true **12.9 alloy**: Caparo M3×16 (₹4.5/pc, pack 200) or TVS packs of 500–1000 on Moglix (stock unconfirmed). For fast small quantities: ThinkRobotics/Quartz packs of 10 (₹3.5–17/pc). Heat-set inserts: **Quartz ₹3.3–7/pc** is the cheapest seen; ThinkRobotics M3 OOS today.

## 3. SHAFTS, BAR/PLATE STOCK, CARBON FIBRE

### 3a. Ground / hard-chrome shafts (linear rods) and D-shafts

| Item | Brand/Model | Supplier | Price ₹ | GST | Qty | Stock | Key specs | URL | Date | Evidence |
|---|---|---|---|---|---|---|---|---|---|---|
| Ø5 × 1000 | Astro "Super Smooth Hard Chrome plated carbon steel rod" | robokits.co.in | 220 | not stated* | 1 | In stock | hard-chrome carbon steel (hardness not stated) | https://robokits.co.in/mechanical-parts/cnc-router-xyz-axis-part/astro-chrome-plated-steel-rods/astro-super-smooth-hard-chrome-plated-5mm-diameter-carbon-steel-rod-1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 | 2026-09-24 | VERIFIED (listing) |
| Ø6 × 1000 | Astro hard chrome | robokits.co.in | 342 | not stated* | 1 | In stock | – | https://robokits.co.in/mechanical-parts/cnc-router-xyz-axis-part/astro-chrome-plated-steel-rods/astro-super-smooth-hard-chrome-plated-6mm-diameter-carbon-steel-rod-1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 | 2026-09-24 | VERIFIED |
| Ø8 × 1000 | Astro hard chrome | robokits.co.in | 280 | not stated* | 1 | In stock | – | https://robokits.co.in/mechanical-parts/cnc-router-xyz-axis-part/astro-chrome-plated-steel-rods/astro-super-smooth-hard-chrome-plated-8mm-diameter-carbon-steel-rod-1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 | 2026-09-24 | VERIFIED |
| Ø10 × 1000 | Astro hard chrome (RKI-6025) | robokits.co.in | 315 (MRP 415) | not stated* ("GST ITC @18 % of ₹56.7") | 1 | In stock | ESTIMATED ₹/kg: 0.617 kg/m (π/4·10²·7.85 g/cm³) → **≈ ₹511/kg** | https://robokits.co.in/mechanical-parts/cnc-router-xyz-axis-part/astro-chrome-plated-steel-rods/astro-super-smooth-hard-chrome-plated-10mm-diameter-carbon-steel-rod-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 | 2026-09-24 | VERIFIED (PDP) |
| Ø12 × 1000 | Astro hard chrome | robokits.co.in | 353 | not stated* | 1 | In stock | – | https://robokits.co.in/mechanical-parts/cnc-router-xyz-axis-part/astro-chrome-plated-steel-rods/astro-super-smooth-hard-chrome-plated-12mm-diameter-carbon-steel-rod-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 | 2026-09-24 | VERIFIED |
| Ø16 × 1000 | Astro hard chrome | robokits.co.in | 450 | not stated* | 1 | In stock | – | https://robokits.co.in/mechanical-parts/cnc-router-xyz-axis-part/astro-chrome-plated-steel-rods/astro-super-smooth-hard-chrome-plated-16mm-diameter-carbon-steel-rod-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 | 2026-09-24 | VERIFIED |
| Ø6 × 300 | "6mm Smooth Rod 300mm Stainless Steel Linear Shaft" | robocraze.com | 149 | incl | 1 | Available | SS | https://robocraze.com/products/6mm-smooth-rod-300mm-stainless-steel-linear-shaft | 2026-09-24 | VERIFIED |
| Ø8 × 500 | "500mm Chrome Plated Stainless Steel Smooth Rod 8mm" | robocraze.com | 279 | incl | 1 | Available | – | https://robocraze.com/products/500mm-smooth-rod | 2026-09-24 | VERIFIED |
| Ø10 × 400 | "Stainless Steel Smooth Rod Shaft 10 mm x 400 mm" | robocraze.com | 324 | incl | 1 | Available | SS | https://robocraze.com/products/stainless-steel-smooth-rod-shaft-10-mm-x-400-mm | 2026-09-24 | VERIFIED |
| Ø8 / Ø12 × 4000 | "Linear Bearing … C45/GCr15/SUS440C Hard Chrome Plated Rod" | Moglix | 5,321 / 8,388 (ex 5,066 / 7,987) | tax field 18 % but incl/ex ratio = 1.05 (listing inconsistent) | 4 m bar, **MOQ 20** | qty 0 | hard-chrome | https://www.moglix.com/linear-bearing-8mm-4000mm-c45gcr15sus440c-hard-chrome-plated-rod/mp/msne5n81zdq0kl | 2026-09-24 | VERIFIED listing — impractical MOQ |
| Ø15 / Ø20 induction-hardened | – | IB / Moglix / Robokits / Shopify stores | **not found** today (Robokits stops at Ø16) | – | – | – | – | – | 2026-09-24 | NOT FOUND → IndiaMART "hard chrome induction hardened rod" sellers (not fetched – IndiaMART rate-limited) |
| D-shaft | – | all checked stores | **not found** | – | – | – | – | – | 2026-09-24 | NOT FOUND → grind a flat on Astro rod, or order D-cut from CNC service |
| Steel parallel keys | – | IB (search returned only clamps) | **not found** | – | – | – | – | – | 2026-09-24 | NOT FOUND → buy key-steel bar locally / machine |

\* Robokits GST note: see §2a.

### 3b. Aluminium plate/bar, steel bar — ₹/kg (Hindalco / Jindal equivalents)

| Item | Brand/Grade | Supplier | Price ₹/kg | GST | MOQ | Stock | Key specs | URL | Date | Evidence |
|---|---|---|---|---|---|---|---|---|---|---|
| 6061-T6 plate | "Rectangular Aluminium Plate 6061" (make: Hindalco/China/Russia) | IndiaMART — Maxal Impex, Mumbai | 365 /kg (listing) | ? | ? | ? | 0.7–300 mm, grades 6061/6082/7075 | https://dir.indiamart.com/impcat/aluminium-plate-6061.html | 2026-09-24 | UNVERIFIED (lead) |
| 6061-T6 plate | "Aluminium Plate 6061 T6" | IndiaMART — Maharashtra Metal (India), Mumbai | 382 /kg | ? | ? | ? | T6 | same | 2026-09-24 | UNVERIFIED |
| 6061-T6 plate | "ASTM B209 6061 Plate" 5 mm, 4'×8' | IndiaMART — Nenava Metal LLP, Mumbai | 300 /kg | ? | ? | ? | 5 mm T6 | same | 2026-09-24 | UNVERIFIED |
| 6061-T6 plate | "6061 Aluminium Alloy Plates" (cut sizes) | IndiaMART — Swagat Steel & Alloys, Mumbai | 301 /kg | ? | ? | ? | cut sizes offered | same | 2026-09-24 | UNVERIFIED |
| 6061-T6 plate | "Aluminum Alloy 6061 T6 Plate" | IndiaMART — Special Metals, Mumbai | 435 /kg | ? | ? | ? | ASTM B209 | same | 2026-09-24 | UNVERIFIED |
| 6061-T6 plate 6 mm | "Aluminium Plate 6061 T652" | IndiaMART — Vijay Prakash Aeromarine Metals, New Delhi | 552 /kg | ? | ? | ? | 6×1220×3000 | same | 2026-09-24 | UNVERIFIED |
| 6061-T651 thick plate | "Aluminium Plate 6061 T651" | IndiaMART — Solitaire Steel & Engg, Mumbai | 555 /kg | ? | ? | ? | 5–500 mm | same | 2026-09-24 | UNVERIFIED |
| **6061-T6 plate range** | 14 IndiaMART listings | – | **₹260 – ₹555 /kg; median ≈ ₹380–400 /kg** | ? | mill sizes (1220×2440 etc.) | – | – | same | 2026-09-24 | ESTIMATED from UNVERIFIED listings |
| Retail cut Al plate | Invento "300x300x5 mm … 1.3 kg" (alloy not stated) | IndustryBuying | 2,359 (ex 1,999) → **≈ ₹1,815/kg** (2,359 ÷ 1.3) | 18% | 1 pc | ≤6 d | 300×300×5 | https://www.industrybuying.com/plates-invento-IND.PLA.439471378 | 2026-09-24 | VERIFIED price / ESTIMATED ₹/kg |
| Retail cut Al plate | Invento 100×100×5 / 150×150×5 | IndustryBuying | 530 / 919 | 18% | 1 | ≤6 d | alloy n/s | https://www.industrybuying.com/plates-invento-FAM281047 | 2026-09-24 | VERIFIED |
| 6061 round rod 6–75 mm | "Round Aluminum Rod 6061" | IndiaMART — Mallinath Metal, Mumbai | 230 /kg (listing) | ? | ? | ? | 6061 | https://dir.indiamart.com/impcat/aluminium-round-bar.html | 2026-09-24 | UNVERIFIED (lead) |
| 6082 round bar (HE30) | "6082 Aluminium Round Bar" 25 mm / "12mm Aluminum 6082 T651 Round Rods" | IndiaMART — Solitaire Steel & Engg / Jagdish Metal, Mumbai | 300 /kg | ? | 6 m lengths | ? | 6082 (T651) | same | 2026-09-24 | UNVERIFIED |
| 6063 / HE9 rod | Special Metals (6063-T6) / Overseas Al (HE9 20 mm) / Grand Metal (6063) | IndiaMART, Mumbai | 425 / 325 / 200 /kg | ? | ? | ? | 6063 = softer extrusion alloy | same | 2026-09-24 | UNVERIFIED |
| **Al round bar range** | 12 IndiaMART listings | – | **₹200 – ₹425 /kg (6061/6082 ≈ ₹230–300)**; 2024 rod ₹650/kg | ? | – | – | – | same | 2026-09-24 | ESTIMATED from UNVERIFIED listings |
| 6061 round bar (other) | web-search snippets: "Aluminium Round Bar 6061 at ₹430/kg" (Ahmedabad), "6061 Aluminum Round Bar at ₹215/kg" (Mumbai) | IndiaMART | 215 – 430 /kg | ? | ? | ? | – | https://www.indiamart.com/proddetail/60mm-aluminium-round-rod-23924684712.html ; https://www.indiamart.com/proddetail/aluminum-round-6061-t6-bar-4454281948.html | 2026-09-24 | UNVERIFIED (snippets; pages not opened) |
| EN8 round bar | "En8 Round Steel Bars, 16mm" etc. | IndiaMART — Fortran Steel (Navi Mumbai), Maxell Steel, Dhand Steel … | 50 – 95 /kg (black/bright) | ? | often 1–2 t | ? | EN8 | https://dir.indiamart.com/impcat/en8-bright-bar.html | 2026-09-24 | UNVERIFIED |
| EN24 round bar | "EN24 Bright Round Bar" (Sunflag) / "EN-24 Round Bar" 12 mm / "EN24 Black Round Bars" | IndiaMART — K.R. Steel Udyog (Howrah) / Pramod Steel (Mumbai) / Steelloys India (Mumbai) | 91 / 140 / 55 /kg | ? | mill lengths 3–6 m | ? | EN24 (Ni-Cr-Mo) | https://dir.indiamart.com/impcat/en24-round-bar.html | 2026-09-24 | UNVERIFIED |
| **EN24 range** | 12 listings | – | **₹55 – ₹150 /kg** | ? | – | – | – | same | 2026-09-24 | ESTIMATED from UNVERIFIED |
| SS304 round bar | – | IB / Moglix / IndiaMART (rate-limited) | not captured | – | – | – | – | – | 2026-09-24 | NOT FOUND (IndiaMART likely; not fetched) |

### 3c. Carbon-fibre tubes & plates (limb tubes)

| Item | Brand/Model | Supplier | Price ₹ | GST | Qty | Stock | Key specs | URL | Date | Evidence |
|---|---|---|---|---|---|---|---|---|---|---|
| CF round tube 24×22×1000 (1.0 wall) | Shenzhen GDC "3K Twill Roll Wrapped CF Hollow Round Tube – Gloss" | thinkrobotics.com | **1,889.99** | displayed | 1 | Available | roll-wrapped 3K twill | https://thinkrobotics.com/products/high-quality-3k-twill-roll-wrapped-carbon-fibre-hollow-round-tube-gloss | 2026-09-24 | VERIFIED (Shopify product JSON; SKU MEC52.24.22.1000) |
| CF round tube 20×1.0×1000 | same | thinkrobotics.com | 1,619.99 | displayed | 1 | Available | – | same | 2026-09-24 | VERIFIED |
| CF round tube 28×1.0×1000 | same | thinkrobotics.com | 2,159.99 | displayed | 1 | Available | – | same | 2026-09-24 | VERIFIED |
| CF round tube 30×2.0×500 | same | thinkrobotics.com | 2,149.99 | displayed | 1 | Available | – | same | 2026-09-24 | VERIFIED |
| CF round tube 18×1.0×1000 / 12×1.5×1000 | same | thinkrobotics.com | 1,479.99 / 1,479.99 | displayed | 1 | Available | – | same | 2026-09-24 | VERIFIED (most 6–16 mm variants OOS today) |
| CF pultruded tube 20×16×1000 | Shenzhen GDC "Precision CF Pultruded Hollow Tube" | thinkrobotics.com | 3,399.99 | displayed | 1 | Available (all smaller sizes OOS) | pultruded | https://thinkrobotics.com/products/precision-carbon-fiber-pultruded-hollow-tube | 2026-09-24 | VERIFIED |
| CF plate 100×250×3 / 400×400×1 / 400×400×3 | Shenzhen GDC "3K Twill … CF Plate/Sheet" | thinkrobotics.com | 1,879.99 / 6,199.99 / 12,299.99 | displayed | 1 | Available | 3K twill | https://thinkrobotics.com/products/high-quality-3k-twill-roll-wrapped-carbon-fibre-plate-sheet | 2026-09-24 | VERIFIED |
| CF sheet 300×300×2 | "High-Strength Carbon Fiber Sheets" | IndiaMART — Nikol Advance Materials, Ahmedabad | 2,000 /sheet | ? | ? | ? | twill | https://dir.indiamart.com/impcat/carbon-fiber-sheet.html | 2026-09-24 | UNVERIFIED |
| CF sheet 350×350×3 | "Carbon Fiber Composites Polymer Sheet" | IndiaMART — Funique Composites, New Delhi | 2,499 /sheet | ? | ? | ? | for drones/robotics | same | 2026-09-24 | UNVERIFIED |
| CF sheet 500×500×2 | "2mm Carbon Fiber Sheet" | IndiaMART — Carbon Fiber Unique, New Delhi | 2,800 /sheet | ? | ? | ? | twill | same | 2026-09-24 | UNVERIFIED |
| CF sheet 300×300×1 | RS PRO 7648703 | IndustryBuying | 28,319 | 18% | 1 | ≤20 d | – | https://www.industrybuying.com/special-washer-rs-pro-FAS.FLA.820518005 | 2026-09-24 | VERIFIED (≈10× IndiaMART — avoid) |

ESTIMATED CF ₹/kg (ρ ≈ 1.55 g/cm³): tube 24×22×1000 → wall area π/4·(24²−22²) = 72.3 mm² → 72.3 cm³ → 0.112 kg → ₹1,890/0.112 ≈ **₹16,900/kg**; ThinkRobotics plate 400×400×1 → 160 cm³ → 0.248 kg → ≈ **₹25,000/kg**; IndiaMART Nikol 300×300×2 → 180 cm³ → 0.279 kg → ≈ **₹7,200/kg** (unverified).

---

## 4. TRANSMISSION PARTS

| Item | Brand/Model | Supplier | Price ₹ | GST | Qty | Stock / lead | Key specs | URL | Date | Evidence |
|---|---|---|---|---|---|---|---|---|---|---|
| GT2 open belt, 6 mm | "GT2 Timing Belt With Steel Cords 2mm Pitch – 1Meter" | robokits.co.in | 46 /m | not stated* | 1 m | In stock | steel cord | https://robokits.co.in/3d-printer/accessories/gt2-timing-belt-2mm-pitch-1meter | 2026-09-24 | VERIFIED |
| GT2 open belt 4 m | Invento ISC 021-2 | IndustryBuying | 931 (ex 789) → 233/m | 18% | 4 m | ≤6 d | 6 mm | https://www.industrybuying.com/timing-belt-invento-FAM281141 | 2026-09-24 | VERIFIED |
| GT2 closed loop 280 / 400 / 610 mm | Robokits | robokits.co.in | 82 / 142 / 107 | not stated* | 1 | In stock (200 mm OOS) | 6 mm | https://robokits.co.in/automation-control-cnc/gt-timing-wheels-pulley-and-belt/gt2-6mm-closed-timing-belt-280mm (400/610 mm: same path, -400mm / -610mm) | 2026-09-24 | VERIFIED |
| GT2 closed 280 mm | Quartz | quartzcomponents.com | 66 | displayed | 1 | Available | 6 mm | https://quartzcomponents.com/products/gt2-timing-belt-280mm-6mm-width-closed-loop-rubber-belt-for-3d-printer | 2026-09-24 | VERIFIED |
| GT2 pulley 20T idler / 40T / 60T / 80T | Robokits | robokits.co.in | 89 / 128 / 220 / 419 | not stated* | 1 | In stock | 5 mm bore (20T, 40T) | https://robokits.co.in/automation-control-cnc/gt-timing-wheels-pulley-and-belt/aluminum-gt2-timing-pulley-for-6mm-belt-40-tooth-5mm-bore ; …/gt2-synchronous-wheel-timing-pulley-60t ; …/gt2-synchronous-wheel-timing-pulley-80t ; https://robokits.co.in/robot-parts/belts-and-pulleys/aluminum-gt2-timing-idler-pulley-for-6mm-belt-20-tooth-5mm-bore | 2026-09-24 | VERIFIED |
| HTD 3M closed belts 6 mm | Contitech HTD 150-3M-06 … 216-3M-06 | IndustryBuying | 919 – 1,002 each | 18% | 1 | **≤120 d** | 3M, 6 mm | https://www.industrybuying.com/timing-belt-contitech-AUT.TIM.934183373 | 2026-09-24 | VERIFIED (slow, pricey) |
| HTD 5M closed belts | Contitech 225-5M-15 … 1500-5M-09 | IndustryBuying | 2,241 – 3,657 | 18% | 1 | ≤120 d | 5M | https://www.industrybuying.com/timing-belt-contitech-AUT.TIM.234183442 | 2026-09-24 | VERIFIED |
| HTD 5M pulleys | OPTIBELT 5M 9/15/25 mm | IndustryBuying | 3,539 – 4,011 | 18% | 1 | ≤120 d | steel | https://www.industrybuying.com/pulleys-optibelt-AUT.PUL.935154968 | 2026-09-24 | VERIFIED (→ print HTD pulleys instead) |
| Spur gear m0.5 (POM) | RS PRO 5217130 (48T, 5 bore) etc. | IndustryBuying | 648 – 848 each | 18% | 1, MOQ 2–4 | ≤20 d | POM, m0.5 | https://www.industrybuying.com/transmission-parts-rs-pro-AUT.TRA.320373225 | 2026-09-24 | VERIFIED |
| Spur gear m1.5 (printed plastic) | Invento ISC 2035-1 … | IndustryBuying | 294 – 636 | 18% | 1 | ≤6 d | 3D-printed, m1.5 | https://www.industrybuying.com/plastic-gears-invento-FAM280740 | 2026-09-24 | VERIFIED |
| Steel/brass m0.5–1 gears, ring gears | – | all checked stores | **not found** | – | – | – | – | – | 2026-09-24 | NOT FOUND → print (PA-CF) or CNC/hob via service |
| Rod end M5 (male/female, RH/LH) | N2K POS5 / POS5L / PHS5 / PHS5L | bearinghouse.in | **141.60** (ex 120) | 18% | 1 | In stock | 5 mm bore, M5 | https://bearinghouse.in/shop/n2k-pos5-rod-end-bearing/ | 2026-09-24 | VERIFIED |
| Rod end M6 / M8 | N2K POS6 / POS8, PHS6L / PHS8L | bearinghouse.in | 141.60 / 177.00 | 18% | 1 | In stock | – | https://bearinghouse.in/shop/n2k-pos6-rod-end-bearing/ | 2026-09-24 | VERIFIED |
| Rod end M5 (THK) | THK POS5 / BL5DA link ball | IndustryBuying | 1,769 / 1,533 | 18% | 1 | ≤19 d | genuine THK | https://www.industrybuying.com/rod-end-bearings-thk-BEA.ROD.638143236 | 2026-09-24 | VERIFIED (10× N2K) |
| Rod end M5 (IKO) | IKO PHSA5 | IndustryBuying | 1,887 | 18% | 1 | ≤19 d | die-cast female | https://www.industrybuying.com/special-bearing-iko-BEA.SPE.238949105 | 2026-09-24 | VERIFIED |
| M3/M4 ball links (RC type) | – | Robocraze / ThinkRobotics / Quartz / IB | **not found** | – | – | – | – | – | 2026-09-24 | NOT FOUND (robu.in not checked) |
| Linkage rod M4 / M5 (threaded, SS304) | Invento ISC 468 (M4×300) / ISC 469 (M5×300) | IndustryBuying | 577 / 600 per pack of 2 | 18% | 2 | ≤6 d | SS304 fully threaded | https://www.industrybuying.com/threaded-rod-invento-FAM104784 ; https://www.industrybuying.com/threaded-rod-invento-FAM104785 | 2026-09-24 | VERIFIED |
| Spherical plain bearing | FBJ GE12-2RS / N2K GE15ES-2RS / N2K GE17 / GE20 | bearinghouse.in | 177.00 / 159.30 / 177.00 / 212.40 | 18% | 1 | In stock | for printed ankle-linkage rods | https://bearinghouse.in/shop/fbj-ge-12-spherical-plain-bearings/ | 2026-09-24 | VERIFIED |
| Ball & socket M5 | RS PRO 689394 | IndustryBuying | 3,185 per 4 | 18% | bag of 4 | ≤15 d | steel | https://www.industrybuying.com/socket-sets-rs-pro-HAN.SOC.820471105 | 2026-09-24 | VERIFIED (expensive) |
| Neodymium disc 8×2 / 8×5 / 10×10 | Quartz NdFeB (grade & magnetisation not stated) | quartzcomponents.com | 13 / 23 / 57 | displayed | 1 | Available | axial assumed — **confirm** | https://quartzcomponents.com/products/small-magnets-8mm-diameter | 2026-09-24 | VERIFIED (price) |
| AS5600 encoder module (check whether a diametric magnet is included) | Quartz | quartzcomponents.com | 122 | displayed | 1 | **Out of stock** | – | https://quartzcomponents.com/products/as5600-magnetic-angle-encoder-sensor-module | 2026-09-24 | VERIFIED |
| Diametric N52 6×2.5 | – | all checked stores | **not found** | – | – | – | – | – | 2026-09-24 | NOT FOUND (robu/AliExpress – other agent) |
| Arc magnets N35–N52 | – | all checked stores | **not found** | – | – | – | – | – | 2026-09-24 | NOT FOUND |
| Compression springs | STANDARD SS.37xx | IndustryBuying | 16 each (ex 15) | 5% | 1, **MOQ 100** | ≤3 d | spec only by code | https://www.industrybuying.com/compression-spring-standard-FAS.SPR.103168756 | 2026-09-24 | VERIFIED |
| Compression springs | RS PRO 751360 (15.7×2.75, 0.22 N/mm) etc. | IndustryBuying | 36 – 44 each | 5% | MOQ 10–20 | ≤20 d | alloy steel, rate given | https://www.industrybuying.com/compression-spring-rs-pro-FAS.COM.320948167 | 2026-09-24 | VERIFIED |
| Belt-tension spring Ø4.8 | Robokits | robokits.co.in | 3 each, MOQ 10 | not stated* | – | In stock | – | https://robokits.co.in/3d-printer/accessories/3d-printer-belt-tightening-spring-diameter-4.8mm-moq-10-pcs | 2026-09-24 | VERIFIED |

---
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

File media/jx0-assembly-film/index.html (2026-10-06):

JX0

THE WALKING, TALKING STS3215 HUMANOID YOU CAN BUILD AT HOME

46 CM · 2.88 KG · 17 STS3215 JOINTS · 3D-PRINTED · ₹58K IN PARTS

39 PARTS.

LET’S BUILD IT.

STEP 01 / 13 · LEGS

Pelvis + hip-yaw servos

PETG, printed near-solid · 2 × STS3215 in cages · thrust rings + keeper bosses

STEP 02 / 13 · LEGS

Hip-yaw discs + keepers

disc on the yaw horn · keeper lip under its rim · held from both sides

STEP 03 / 13 · LEGS

Hip-roll servos

2 × STS3215 · caged behind the hip

STEP 04 / 13 · LEGS

Hip-roll U-brackets

on the horn and the rear hub · double-sided

STEP 05 / 13 · LEGS

Hip-pitch servos

2 × STS3215 · axis through the hip centre

STEP 06 / 13 · LEGS

Thighs + knee servos

dog-leg U-bracket · knee servo lying forward

STEP 07 / 13 · LEGS

Shins + ankle-pitch servos

U-bracket on the knee · ankle servo caged below

STEP 08 / 13 · LEGS

Ankle brackets + roll servos

U-bracket on the ankle-pitch servo · roll cage behind the ankle

STEP 09 / 13 · LEGS

Feet

chamfered 124 × 70 mm soles · U-bracket on the roll servo

STEP 10 / 13 · BODY

Torso

octagonal shell · skirt over the hip-yaw servos · Pi 4, battery, servo driver inside

STEP 11 / 13 · ARMS

Arms

shoulder servo in a hood · elbow servo below · 6 mm paddle blades

STEP 12 / 13 · HEAD

Chest cap + neck servo

speaker grille · vents · neck STS3215 on top

STEP 13 / 13 · HEAD

Head

soft rounded head · four holes for the microphone

JX0 — ASSEMBLED

46 cm tall · 2.88 kg · 17 STS3215 joints

double-sided leg joints · the hip-yaw disc held from both sides

every printed leg part FEA-checked · walks, talks (Claude)

AND IT WALKS.

MuJoCo simulation of the CAD model · 0.05 m/s

JX0

github.com/nickthelegend/thenar-jx1/tree/main/jx0

CAD · FEA · BOM · SIMULATION · ROBOT CODE — all open. Build one.

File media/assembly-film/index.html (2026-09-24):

JX1

A 1.23 M HUMANOID YOU CAN BUILD IN INDIA

23 DOF · 33.6 KG · 21 ROBSTRIDE ACTUATORS · OPEN CAD, FEA, BOM, SIM

87 PARTS.

LET’S BUILD IT.

STEP 01 / 22 · LOWER BODY

Pelvis torsion box

6061-T6 laser-cut plates · top 6 mm, walls 4 mm · FEA SF 2.90

STEP 02 / 22 · LOWER BODY

Hip-yaw actuators

2 × RobStride RS06 · 36 N·m peak · vertical axis

STEP 03 / 22 · LOWER BODY

Hip-yaw brackets

7075-T6, CNC from 25 mm plate · FEA SF 1.77

STEP 04 / 22 · LOWER BODY

Hip-roll actuators

2 × RobStride RS03 · 60 N·m · axis pointing forward

STEP 05 / 22 · LOWER BODY

Hip-roll brackets

6061-T6 8 + 10 mm plates · FEA SF 2.76

STEP 06 / 22 · LOWER BODY

Hip-pitch actuators

2 × RobStride RS04 · 120 N·m

STEP 07 / 22 · LOWER BODY

Thighs

6061-T6 10 mm plate with run-out flanges · 0.27 m

STEP 08 / 22 · LOWER BODY

Knee actuators

2 × RobStride RS04 · 120 N·m · 0–120° knee

STEP 09 / 22 · LOWER BODY

Shins

6061-T6 14 mm knee plate + web · 0.30 m

STEP 10 / 22 · LOWER BODY

Ankle motors + cranks

4 × RobStride RS06 · 50 mm cranks · parallel ankle

STEP 11 / 22 · LOWER BODY

Ankle cross + feet

steel U-joint on needle bearings · 6061-T6 feet, 210 × 95 mm

STEP 12 / 22 · LOWER BODY

Push-rods

Ø8 steel rods + M5 rod ends · pitch −55…+30°, roll ±20°

STEP 13 / 22 · TORSO + POWER

Waist actuator

RobStride RS06 · waist yaw

STEP 14 / 22 · TORSO + POWER

Torso frame

6061-T6 plates + 4 × 2020 extrusion · FEA SF 4.44

STEP 15 / 22 · TORSO + POWER

Battery + electronics

13S2P 468 Wh · Jetson Nano · 2 × Teensy 4.1 CAN hubs · DC-DC · E-stop

STEP 16 / 22 · ARMS

Shoulder-pitch actuators

2 × RobStride RS02 · 17 N·m

STEP 17 / 22 · ARMS

Shoulder brackets + roll actuators

6061-T6 U-brackets · 2 × RobStride RS02

STEP 18 / 22 · ARMS

Shoulder-yaw actuators

6061-T6 L-brackets · 2 × RobStride RS00 · 14 N·m

STEP 19 / 22 · ARMS

Upper arms + elbows

6061-T6 10 / 8 mm plates + gussets · 2 × RobStride RS00

STEP 20 / 22 · ARMS

Forearms + grippers

6061-T6 6 mm · PA-CF grippers

STEP 21 / 22 · HEAD

Neck

2 × Waveshare ST3215 bus servos · yaw + pitch

STEP 22 / 22 · HEAD

Head + stereo camera

PETG-CF shell · IMX219-83 stereo camera

JX1 — ASSEMBLED

1.23 m tall · 33.6 kg · 23 degrees of freedom

12-DOF legs · 2-motor parallel ankles · 48 V CAN actuators

Aluminium structure · every part FEA-checked

AND IT WALKS.

MuJoCo simulation of the CAD model · ZMP gait · 0.52 m/s

JX1

github.com/nickthelegend/thenar-jx1

CAD · FEA · BOM · SIMULATION · RL — all open. Build one.

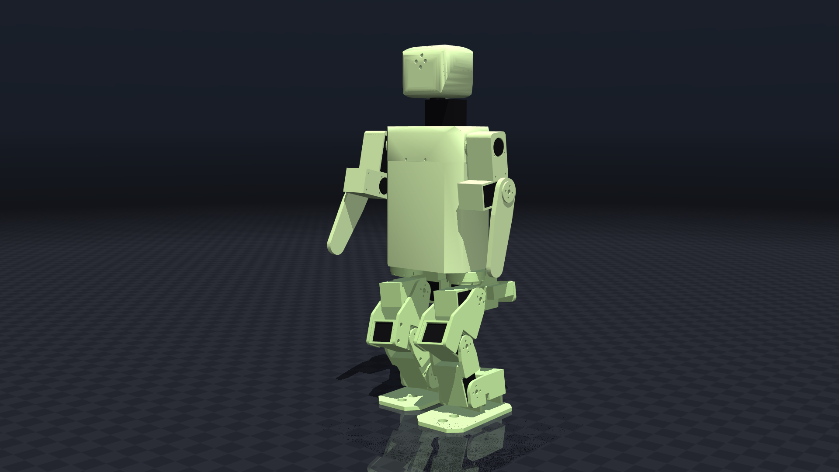
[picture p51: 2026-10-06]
jx0/docs/images/jx0_assembly_walking.png

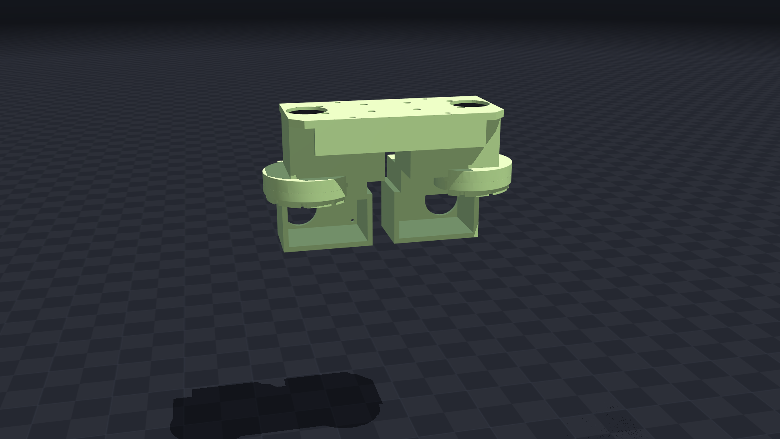
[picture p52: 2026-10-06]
jx0/docs/assembly/step_02.png

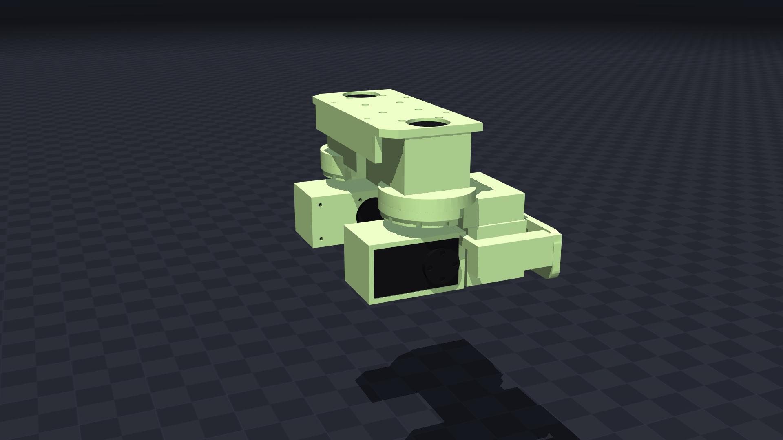
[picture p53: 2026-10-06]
jx0/docs/assembly/step_05.png

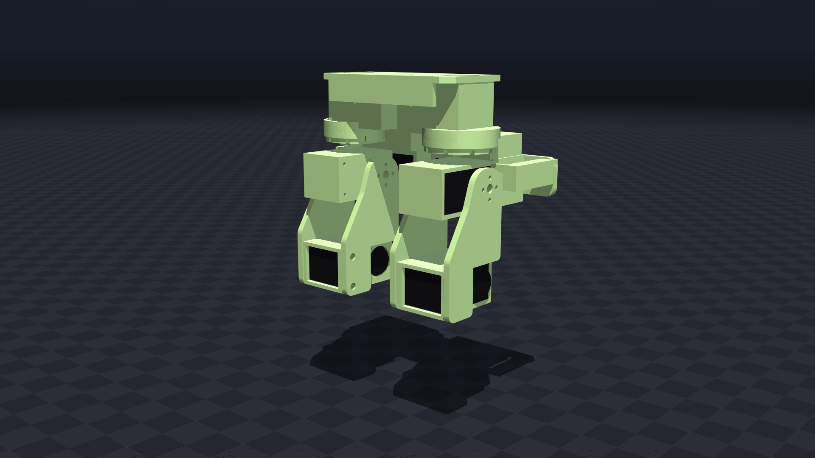
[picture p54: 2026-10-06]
jx0/docs/assembly/step_06.png

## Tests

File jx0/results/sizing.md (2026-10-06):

# JX0 servo sizing (CALCULATED (servo data and masses ASSUMED until measured))

Design `jx0/design_point.yaml`, total mass 2.88 kg, walking hip height 0.14 m. Servo: Feetech STS3215 12 V serial bus servo (ST3215-C018 / Waveshare ST3215; 30 kg·cm stall, 10 kg·cm rated at 12 V); stall 2.94 N·m, rated 0.98 N·m (assumed 1/3 of stall), no-load 4.72 rad/s.
Checks: 1.5 x dynamic peak (1.25 x static) <= stall; 1.3 x walking RMS <= rated; 1.5 x torque within the linear torque-speed line at every sample.

| Joint | Dynamic peak N·m (scenario) | Static peak N·m (case) | Required peak | Peak margin | Walking RMS | Continuous margin | Peak speed rad/s | Torque-speed use | Pass |
|---|---|---|---|---|---|---|---|---|---|
| hip_yaw | 0.094 (turn_10deg_per_step) | 0.0 (stand_double) | 0.142 | 20.75 | 0.017 | 45.4 | 0.73 | 5 % (turn_10deg_per_step) | yes |
| hip_roll | 1.331 (turn_10deg_per_step) | 1.608 (single_leg_cop_outer_edge) | 2.01 | 1.46 | 0.667 | 1.13 | 1.59 | 83 % (walk_brisk_0.055ms) | yes |
| hip_pitch | 0.247 (walk_brisk_0.055ms) | 0.188 (single_leg_cop_toe) | 0.371 | 7.93 | 0.093 | 8.07 | 3.52 | 19 % (walk_brisk_0.055ms) | yes |
| knee | 0.706 (turn_10deg_per_step) | 1.059 (single_leg_cop_inner_edge) | 1.323 | 2.22 | 0.386 | 1.95 | 4.01 | 68 % (walk_brisk_0.055ms) | yes |
| ankle_pitch | 0.259 (walk_brisk_0.055ms) | 1.291 (single_leg_cop_heel) | 1.614 | 1.82 | 0.093 | 8.09 | 3.57 | 25 % (walk_brisk_0.055ms) | yes |
| ankle_roll | 0.646 (turn_10deg_per_step) | 0.846 (single_leg_cop_inner_edge) | 1.058 | 2.78 | 0.304 | 2.48 | 1.59 | 45 % (turn_10deg_per_step) | yes |

| Scenario | ZMP tracking error (mm) |
|---|---|
| walk_slow_0.042ms | 2.05 |
| walk_nominal_0.05ms | 2.15 |
| walk_brisk_0.055ms | 2.3 |
| turn_10deg_per_step | 2.32 |
| squat_2.5cm_1.6s | 0.56 |

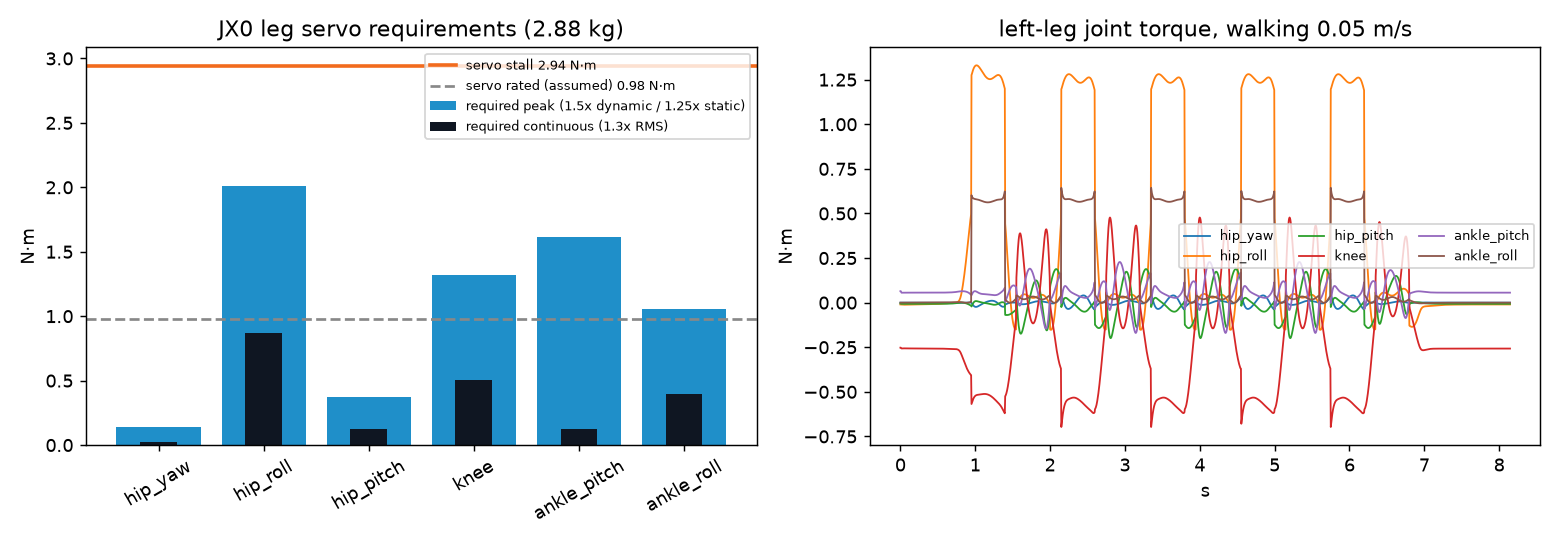
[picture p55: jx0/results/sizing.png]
sizing


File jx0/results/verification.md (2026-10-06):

# JX0 verification report

Generated 2026-10-06 by `jx0/verify/run_all.py` from the CAD geometry, the MuJoCo model and the robot software in this repository (design v0.4: double-sided legs like the reference robot). Everything here is simulation and analysis: the physical robot is not built yet, so the numbers say the design should work, not that it has been seen working.

## Summary

| Check | Result |
|---|---|
| Servo sizing (every leg joint, 5 gaits + 8 static cases, 1.25–1.5x margins) | **ALL PASS** |
| The 14 robot gaits, closed loop on the servo model (100 Hz) | **14/14 pass**, peak servo load 55% of stall |
| Parts and servos colliding, standing (all 741 pairs) | 0 clashes |
| Parts colliding in motion (1373 poses: every gait frame + every action) | 0 clashes |
| Joint limits inside the collision-free range | 17/17 joints |
| Leg joints: single-sided (v0.3) vs double-sided (v0.4), beam model, fatigue safety factor | v0.3 0.21–0.48 (**would break**) → v0.4 **4.4–7.5** |
| Printed leg brackets, voxel FEA under the simulated loads, worst bracket | fatigue SF **2.1**, strength SF **3.0** |
| Walking with realistic model errors (latency 0–20 ms), all gaits | **138/140 (99 %)** |
| Same, stress test with 40 ms latency | 123/140 (88 %) |
| Sideways push of 0.24 N.s mid-walk (24 moments × 2 directions): stayed up | 48/48 (100 %) |
| Sideways push of 0.48 N.s mid-walk (24 moments × 2 directions): stayed up | 48/48 (100 %) |
| Sideways push of 0.72 N.s mid-walk (24 moments × 2 directions): stayed up | 48/48 (100 %) |
| Sideways push of 0.96 N.s mid-walk (24 moments × 2 directions): stayed up | 48/48 (100 %) |
| Sideways push of 1.20 N.s mid-walk (24 moments × 2 directions): stayed up | 43/48 (90 %) |
| Sideways push of 1.44 N.s mid-walk (24 moments × 2 directions): stayed up | 21/48 (44 %) |
| Whole robot program, 8-step mission, random realistic errors | **24/24 (100 %)** |
| Battery current walking (servos + Pi) | 1.45 A average, 2.52 A peak → about 73 min walking per charge |
| 100 Hz control loop on a Raspberry Pi 4 (estimated) | 1.8 ms of 10 ms |
| Software unit tests | Ran 21 tests in 5.663s: OK |

## Leg joints: why double-sided

Every leg joint's load from the simulation (14 gaits, 42 walks with model errors, 48 pushes of 0.96 N·s), and what it does to a single-sided joint (v0.3: one plate on the servo's horn) and to a U-bracket on both faces (v0.4). The servo only *drives* the torque about its axis; the bending moment about the other two axes is what the structure carries. On a single-sided joint it all goes through one printed plate and the servo's output shaft. In a U-bracket it becomes a pair of forces in the two arms, 42.75 mm apart, and the output shaft sees no bending at all. The hip-yaw disc is held by the pelvis from both sides instead (thrust ring above, keeper below): its stresses are in the finite-element table. PETG ASSUMED: 50 MPa static, 15 MPa fatigue (10^6 cycles, about 700 hours of walking).

| Joint | Torque N·m | Bending at the horn N·m | v0.3 plate MPa (fatigue SF) | v0.4 MPa (fatigue SF) | Servo shaft bending N·m, v0.3 → v0.4 |
|---|---|---|---|---|---|
| hip yaw | 1.08 | 3.03 | 55.0 (0.27) | ring + keeper: 120 / 100 N pushes on the disc rim (FEA below) | 3.03 → 2.6 (ring only) → 0.55 |
| hip roll | 2.80 | 2.40 | 31.3 (0.48) | 2.0 (7.5) | 2.4 → 0.0 |
| hip pitch | 1.90 | 3.79 | 39.7 (0.38) | 3.3 (4.5) | 3.79 → 0.0 |
| knee | 2.50 | 3.36 | 33.7 (0.45) | 3.4 (4.4) | 3.36 → 0.0 |
| ankle pitch | 2.44 | 3.14 | 49.4 (0.3) | 2.9 (5.2) | 3.14 → 0.0 |
| ankle roll | 1.85 | 3.59 | 70.9 (0.21) | 2.8 (5.4) | 3.59 → 0.0 |

## Printed leg brackets: finite elements

Voxel FEA (`calculations/structural/voxel_fea.py`, 0.7 mm hexahedra with bending modes). Each bracket is held where it bolts to the servo above it (horn and rear hub) and loaded where the next servo is screwed into its cage, with that joint's actual 6-axis load every 10 ms of the simulation (all components at the same instant). Stress = 99.9th percentile of each element's worst von Mises, away from the bolted faces.

| Bracket | Elements | Walking MPa (fatigue SF) | Worst with pushes MPa (strength SF) |
|---|---|---|---|
| pelvis | 224,820 | 6.21 (2.4) | 9.77 (5.1) |
| yaw keeper | 8,022 | 7.07 (2.1) | 9.59 (5.2) |
| hip yaw bracket | 146,407 | 6.19 (2.4) | 13.76 (3.6) |
| hip roll bracket | 84,757 | 5.62 (2.7) | 13.4 (3.7) |
| thigh | 124,302 | 6.65 (2.3) | 14.83 (3.4) |
| shin | 73,504 | 6.06 (2.5) | 16.2 (3.1) |
| ankle bracket | 104,758 | 6.23 (2.4) | 16.68 (3.0) |
| foot | 142,492 | 3.13 (4.8) | 7.74 (6.5) |

Stress maps: `images/fea_*.png`.

## What the verification found and fixed

### v0.4 (double-sided legs, 2026-10-05)

- **Single-sided joints would break** (the builder's own call, confirmed): with v0.4's loads, a v0.3-style joint's printed plate sees 31–71 MPa every step, above PETG's fatigue strength at every leg joint, and the servo's output shaft carries up to 3.8 N·m of bending. Every leg pitch and roll joint is now a U-bracket on the servo's horn and rear hub, the servo body screwed into a cage, like the reference robot.
- **The first U-brackets had weak joints between the arms and the next servo's cage** (voxel FEA): the shin's arms met the ankle cage through two 18 × 3 mm tabs, the ankle bracket through 2.5 mm bands, the hip-yaw disc through a thin plate. Solid plates now join each arm to its cage over the whole overlap; cage rear plates went from 2.4 to 4 mm (screw heads counterbored), arms from 3.5 to 4.5 mm; the hip-yaw bracket got a 7 mm disc, a keel and a solid block; the hip-roll bracket a 10 × 16 mm bridge.
- **The final masses (2.85 kg) raised the loads by about a tenth**, and two spots fell below a safety factor of 2: the shin's back plate beside the ankle servo's hub hole (strength 1.9: a screw counterbore 0.1 mm from the hole, no side wall at that corner) and the ankle bracket's inboard arm where it meets the roll cage (fatigue 1.8). The shin's plate is now 4 mm everywhere the ankle bracket's boss does not slide, with a 20 mm hub hole and that one screw left out; the ankle bracket's inboard arm reaches 4.5 mm lower (the foot's bracket only comes within 12 mm below the axis there): shin 2.5 / 3.2, ankle bracket 2.4 / 3.0.
- **The hip-yaw servo's shaft still carried the leg's bending** (the builder asked for the retainer lip): a thrust ring alone left it 1.2 N·m in normal walking and 2.6 N·m in the hardest pushes. Now the pelvis holds the yaw disc from both sides: a printed keeper (one per leg, 4 M2 screws into a new boss on the pelvis) puts a lip under the disc's 3 mm flange on the arc where the load needs it. The first keeper failed its own check (fatigue SF 0.5: a 2.2 mm lip, then notches at its ends), so it became a solid C-section clamped to the boss; the pelvis's yaw cages got 5 mm front and back walls to carry its pull (SF 1.3 → 2.5). The hip-yaw range is now ±12° (the gaits use ±5°): over ±30° the hip-roll bracket would reach the keeper, and the legs touched each other beyond 18°.
- **Assembly**: plates that cover a cage would have locked the servo out. The knee cage is open at the front and the ankle cage at the bottom (the servos slide in there), with screwdriver holes through the arms for the far case screws.
- **Shorter legs swayed 26° sideways and pushed the ankle-roll servo against its stop** (100 % of stall): the gaits now keep the zero-moment point 20 mm inside each foot (planner option `zmp_offset_y`, chosen by Monte Carlo over 0–20 mm and 0.45–0.6 s steps): 15° at most, 50 % peak load.
- **Knee speed**: with 62/58 mm leg links the knee swings faster; 0.5 s steps reach the servo's no-load speed. The gaits keep 0.6 s steps (sizing: 68% of the torque-speed line at 0.55 s).
- **Collision ranges re-measured** for every joint; limits set inside them (left leg: hip roll −20…22°, hip pitch −70…8°, knee 0…84°, ankle roll ±20°; every range the gaits use is inside).

### v0.3 (2026-10-04)

- Shoulder servos inside the chest cap; a hip gusset into the hip-pitch servo; the foot grazing the ankle-pitch servo; ankle brackets touching in side-steps; limits allowing collisions — all fixed then. Walking robustness: 100 Hz control, a lower stance, 2- and 4-step blocks. An over-claimed push result (one lucky timing) and a wrong battery estimate were corrected.

## Honest limits

- **Pushes**: 0.24 N.s stays up 100 %, 0.48 N.s stays up 100 %, 0.72 N.s stays up 100 %, 0.96 N.s stays up 100 %, 1.20 N.s stays up 90 %, 1.44 N.s stays up 44 % of 48 timed pushes mid-walk. Harder shoves need a step to a new place; the gait player does not re-plan its steps (a capture-point stepper is in `jx0bot/stepper.py`, not yet enabled).
- **The hip-yaw keeper only works without play**: the analysis assumes the ring and the keeper's lip touch the yaw disc (PTFE tape on the flange, added until the leg turns freely with no wobble). With the keeper, the yaw servo's shaft is left about 0.10 N·m in normal walking and 0.55 N·m in the hardest pushes (ring alone: 1.2 / 2.6); if the play is left in, the shaft takes the bending until it closes. Feetech publishes no bending rating for the STS3215. The yaw range is ±12°.
- **Material and servo data are assumed**: PETG strengths (50 / 15 MPa), the STS3215's rear hub screw pattern (assumed equal to the horn's), and the servo stiffness (60 N·m/rad, 0.6–1.4x tested). Print a test U-bracket and fit-check a servo before printing the rest; measure the servo stiffness (bringup.md step 5).
- **Speed**: about 5 cm/s. The short legs make the knee the speed limit of the STS3215 at 12 V.
- **Latency**: the robot needs its control loop to react within about 20 ms (estimate on the Pi: about 8 ms). At 40 ms, long walks often fail; 2- and 4-step blocks mostly survive.
- **Not tested here**: falls (the model has no body collisions, so a fall's impact on the brackets is not simulated), carpet or very slippery floors (friction below 0.5), stairs, the I2S audio overlay on the Pi, screw fit in the printed holes, long-term servo heating.

## Re-run

```bash
python jx0/verify/run_all.py
```

Detailed results in this folder: `walking.json`, `verify_cad.json`, `verify_robustness.json`, `verify_strength.json`, `verify_fea.json`, `verify_power.json`, `sizing.json`.

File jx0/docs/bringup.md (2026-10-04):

# JX0 bring-up: from a box of servos to the first steps

Go slowly: the STS3215s are strong enough to break printed parts or pinch fingers. Keep the robot on a stand (legs
hanging free) until step 6, and keep a hand on the power switch. A 12.6 V bench supply with a 3 A current limit is the
gentlest way to power it during bring-up.

All commands run on the Pi from `jx0/software` (see [software_setup.md](software_setup.md)):

```bash
cd ~/thenar-jx1/jx0/software && source ~/jx0env/bin/activate
```

## 1. Give every servo its ID (before assembly)

All 17 STS3215s ship as ID 1. Connect **one servo at a time** to the driver:

```bash
python -m jx0bot.calibrate scan
```

It should list one servo at ID 1, at 11–12.6 V. Then give it its ID, for example the left ankle pitch:

```bash
python -m jx0bot.calibrate set-id 1 5
```

Write the ID on the servo with a marker. The ID table is in [wiring.md](wiring.md): legs 1–12, left shoulder 13,
left elbow 14, right shoulder 15, right elbow 16, neck 17.

## 2. Centre everything, then fit horns and links

With all 17 servos chained:

```bash
python -m jx0bot.calibrate center
```

Every servo goes to mid-travel (2048 ticks). While they hold, fit the horns and printed links so each joint is as close
to its zero pose as the horn splines allow: legs straight, feet flat, shoulder hoods and blades hanging straight down,
head facing forward. Then press Enter to release.

## 3. Record the exact zero pose

```bash
python -m jx0bot.calibrate zero
```

Torque goes off. Hold the robot in the zero pose (a small set square against the pelvis, thigh and shin brackets helps)
and press Enter. All 17 encoder readings are written into `config.yaml` as `zero_ticks`.

## 4. Check every joint's direction

```bash
python -m jx0bot.calibrate directions
```

Each joint moves +10° and back. The tool asks whether it moved the way the simulation expects ("the knee BENDS", "the
arm swings BACKWARD", "the head turns to the robot's LEFT"). Answer y/n and the `direction` values in config.yaml are
updated. **Don't skip this**: one reversed leg joint makes the balance loop push the wrong way.

## 5. Check the stiffness

The walking was verified with servos that give way about 0.5° under a 0.5 N·m load (60 N·m/rad):

```bash
python -m jx0bot.calibrate stiffness l_knee
```

Hang 0.5 kg from a string 10 cm from the knee axis (0.49 N·m), press Enter, and read the stiffness. If it is much softer
than 60, the position gain is too low. Raise the servo's P coefficient with Feetech's FD debugging software (Windows) or
the Waveshare servo tool, then measure again. How the servo's gain register maps to stiffness is **UNVERIFIED**: it is
the first thing to measure on real hardware.

## 6. First stand, first steps

1. On the stand, run `python -m jx0bot.main --text`. The robot moves smoothly from wherever its joints are into its
   walking stance (knees bent). Type "wave" to test the arms.
2. Hold the robot on the floor by a strap on the torso, like a baby walker with the strap slack, and power it up again.
3. Type "walk forward two steps". It plays the gait blocks that passed the simulation check, arms swinging, with the IMU
   balance loop on the stance leg.
4. If it tips, the program stops the gait by itself past 25° of tilt. Check the direction table and the IMU mounting
   (`imu.mount`) before trying again.
5. When it walks reliably, try what the reference video shows: a gentle push from the side while it walks. In the
   simulation a light tap (0.24 N·s) never knocks it over, but a firm shove (0.48 N·s) does about a third of the time,
   so keep your hand ready (results/verification.md).

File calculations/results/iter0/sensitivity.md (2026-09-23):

# Sensitivity study (iter0)

Peak |torque| N·m (`_pk`) and peak |speed| rad/s (`_w`), left+right legs. CALCULATED.

| study | value | gait | mass_kg | hip_roll_pk | hip_pitch_pk | knee_pk | ankle_pitch_pk | hip_pitch_w | knee_w | knee_max_deg | ankle_min_deg | zmp_err_mm |
|:---|---:|:---|---:|---:|---:|---:|---:|---:|---:|---:|---:|---:|
| hip_height | 0.5  | nominal | 25 | 24.2 | 28.6 | 38.7 | 6.1 | 6 | 5.3 | 88.5 | -53.7 | 15.6 |
| hip_height | 0.5  | fast | 25 | 26.3 | 45.8 | 45.2 | 8.6 | 9.6 | 8.6 | 97.1 | -62.1 | 25.2 |
| hip_height | 0.52 | nominal | 25 | 24.2 | 29.2 | 36.1 | 6.1 | 5.9 | 5.6 | 82.6 | -50 | 14.9 |
| hip_height | 0.52 | fast | 25 | 25.9 | 46.9 | 42.6 | 8.7 | 9.3 | 9.1 | 91.5 | -58.4 | 25.6 |
| hip_height | 0.54 | nominal | 25 | 24.2 | 30.2 | 33.4 | 6.3 | 5.9 | 6.1 | 76.2 | -46.1 | 14.9 |
| hip_height | 0.54 | fast | 25 | 26.9 | 49 | 40 | 9.3 | 9.2 | 9.8 | 85.7 | -54.5 | 26.5 |
| hip_height | 0.56 | nominal | 25 | 24.1 | 32.8 | 30.6 | 6.8 | 6 | 6.9 | 69.3 | -42 | 16.6 |
| hip_height | 0.56 | fast | 25 | 29.4 | 56.2 | 38.5 | 13.7 | 9.1 | 10.9 | 79.5 | -50.4 | 27.9 |
| segment_length  | 0.25 | nominal | 25 | 24 | 28.8 | 29.8 | 6.7 | 6.7 | 7.1 | 78.3 | -48.1 | 16.5 |
| segment_length  | 0.25 | fast | 25 | 28.7 | 48.6 | 38.2 | 13 | 10.5 | 11.6 | 88.6 | -57.2 | 28.7 |
| segment_length  | 0.28 | nominal | 25 | 24.2 | 30.2 | 33.4 | 6.3 | 5.9 | 6.1 | 76.2 | -46.1 | 14.9 |
| segment_length  | 0.28 | fast | 25 | 26.9 | 49 | 40 | 9.3 | 9.2 | 9.8 | 85.7 | -54.5 | 26.5 |
| segment_length  | 0.31 | nominal | 25 | 24.3 | 32 | 37.1 | 6 | 5.2 | 5.4 | 74.4 | -44.4 | 16.5 |
| segment_length  | 0.31 | fast | 25 | 25.9 | 51.2 | 44 | 8.5 | 8.1 | 8.5 | 83.2 | -52.2 | 24.5 |
| upper_body_mass | 9 | nominal | 22 | 22.3 | 29.1 | 29.4 | 6 | 5.9 | 6.2 | 76.1 | -45.9 | 23.7 |
| upper_body_mass | 9 | fast | 22 | 25.6 | 47.7 | 35.6 | 9.1 | 9.2 | 9.9 | 85.7 | -54.3 | 28.4 |
| upper_body_mass | 12 | nominal | 25 | 24.2 | 30.2 | 33.4 | 6.3 | 5.9 | 6.1 | 76.2 | -46.1 | 14.9 |
| upper_body_mass | 12 | fast | 25 | 26.9 | 49 | 40 | 9.3 | 9.2 | 9.8 | 85.7 | -54.5 | 26.5 |
| upper_body_mass | 15 | nominal | 28 | 26.1 | 31.2 | 37.4 | 6.6 | 5.9 | 6 | 76.2 | -46.3 | 13.9 |
| upper_body_mass | 15 | fast | 28 | 28.2 | 50.1 | 44.7 | 9.5 | 9.2 | 9.7 | 85.7 | -54.6 | 24.7 |
| knee_actuator_z | -0.28 | nominal | 25 | 24.2 | 30.2 | 33.4 | 6.3 | 5.9 | 6.1 | 76.2 | -46.1 | 14.9 |
| knee_actuator_z | -0.28 | fast | 25 | 26.9 | 49 | 40 | 9.3 | 9.2 | 9.8 | 85.7 | -54.5 | 26.5 |
| knee_actuator_z | -0.14 | nominal | 25 | 23.6 | 24.8 | 33.3 | 5.7 | 5.9 | 6 | 76.2 | -46.5 | 13.2 |
| knee_actuator_z | -0.14 | fast | 25 | 25.3 | 40.1 | 39.9 | 7.9 | 9.2 | 9.5 | 85.7 | -54.8 | 23.6 |
| knee_actuator_z | -0.06 | nominal | 25 | 23.3 | 22.9 | 33.5 | 5.6 | 5.9 | 5.9 | 76.2 | -46.7 | 12.5 |
| knee_actuator_z | -0.06 | fast | 25 | 24.5 | 37.1 | 40.1 | 7.5 | 9.2 | 9.4 | 85.7 | -54.9 | 22.5 |

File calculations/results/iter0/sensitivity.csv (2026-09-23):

study | value | gait | mass_kg | hip_yaw_pk | hip_yaw_w | hip_roll_pk | hip_roll_w | hip_pitch_pk | hip_pitch_w | knee_pk | knee_w | ankle_pitch_pk | ankle_pitch_w | ankle_roll_pk | ankle_roll_w | knee_max_deg | ankle_min_deg | zmp_err_mm
hip_height | 0.5 | nominal | 25.0 | 10.0 | 0.0 | 24.2 | 0.6 | 28.6 | 6.0 | 38.7 | 5.3 | 6.1 | 6.2 | 2.5 | 0.6 | 88.5 | -53.7 | 15.6
hip_height | 0.5 | fast | 25.0 | 18.1 | 0.0 | 26.3 | 0.6 | 45.8 | 9.6 | 45.2 | 8.6 | 8.6 | 9.8 | 2.9 | 0.6 | 97.1 | -62.1 | 25.2
hip_height | 0.52 | nominal | 25.0 | 10.3 | 0.0 | 24.2 | 0.6 | 29.2 | 5.9 | 36.1 | 5.6 | 6.1 | 6.0 | 2.5 | 0.6 | 82.6 | -50.0 | 14.9
hip_height | 0.52 | fast | 25.0 | 18.5 | 0.0 | 25.9 | 0.6 | 46.9 | 9.3 | 42.6 | 9.1 | 8.7 | 9.5 | 3.0 | 0.6 | 91.5 | -58.4 | 25.6
hip_height | 0.54 | nominal | 25.0 | 10.8 | 0.0 | 24.2 | 0.6 | 30.2 | 5.9 | 33.4 | 6.1 | 6.3 | 6.0 | 2.5 | 0.6 | 76.2 | -46.1 | 14.9
hip_height | 0.54 | fast | 25.0 | 19.6 | 0.0 | 26.9 | 0.6 | 49.0 | 9.2 | 40.0 | 9.8 | 9.3 | 9.3 | 3.2 | 0.6 | 85.7 | -54.5 | 26.5
hip_height | 0.56 | nominal | 25.0 | 12.1 | 0.0 | 24.1 | 0.5 | 32.8 | 6.0 | 30.6 | 6.9 | 6.8 | 6.0 | 2.5 | 0.5 | 69.3 | -42.0 | 16.6
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

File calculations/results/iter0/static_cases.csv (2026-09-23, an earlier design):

case | stance | hip_height_m | com_x | com_y | hip_yaw_Nm | hip_yaw_deg | hip_roll_Nm | hip_roll_deg | hip_pitch_Nm | hip_pitch_deg | knee_Nm | knee_deg | ankle_pitch_Nm | ankle_pitch_deg | ankle_roll_Nm | ankle_roll_deg | ankle_motor_Nm
stand_double_nominal | both | 0.54 | 0.015 | 0.0 | 0.0 | -0.0 | 0.574 | 0.0 | 0.505 | -29.68 | 13.181 | 57.89 | 1.736 | -28.22 | 0.0 | 0.0 | 0.868
stand_double_deep_squat | both | 0.34 | 0.015 | 0.0 | 0.0 | -0.0 | 0.574 | 0.0 | 0.505 | -64.43 | 23.599 | 117.27 | 1.736 | -52.84 | 0.0 | 0.0 | 0.868
single_leg_nominal | l | 0.54 | 0.015 | 0.09 | 0.0 | -0.0 | 24.689 | -12.31 | 3.206 | -27.57 | 23.901 | 52.78 | 3.494 | -25.21 | 0.0 | 12.31 | 1.851
single_leg_bent_knee90 | l | 0.44 | 0.015 | 0.09 | 0.0 | -0.0 | 24.549 | -15.21 | 4.384 | -46.97 | 37.893 | 87.42 | 3.451 | -40.45 | 0.0 | 15.21 | 1.96
single_leg_cop_toe | l | 0.5 | 0.125 | 0.09 | 0.0 | -0.0 | 25.111 | -13.69 | 0.827 | -17.08 | 16.274 | 62.79 | 29.685 | -45.71 | 0.0 | 13.69 | 17.077
single_leg_cop_heel | l | 0.5 | -0.065 | 0.09 | 0.0 | -0.0 | 24.345 | -13.1 | 5.202 | -45.28 | 36.279 | 64.12 | 15.627 | -18.84 | 0.0 | 13.1 | 8.147
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

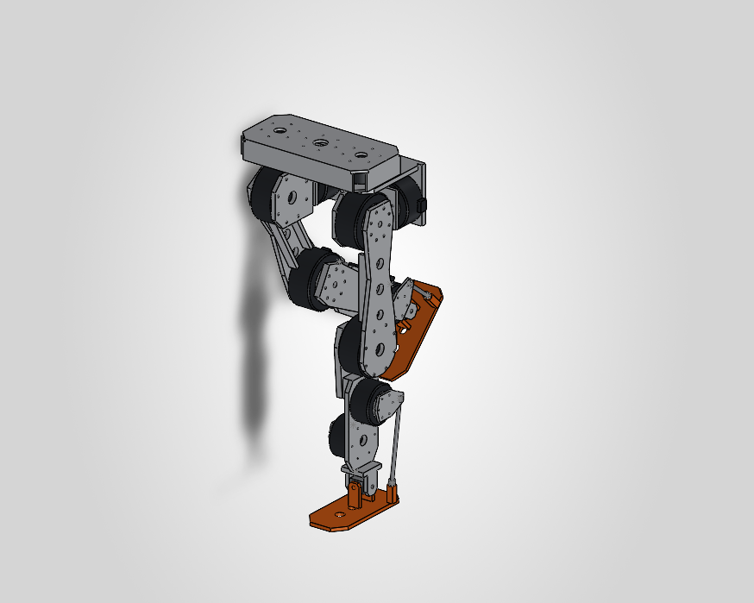
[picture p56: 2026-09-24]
verification/images/poses/JX1_LowerBody_R_leg_backward.png

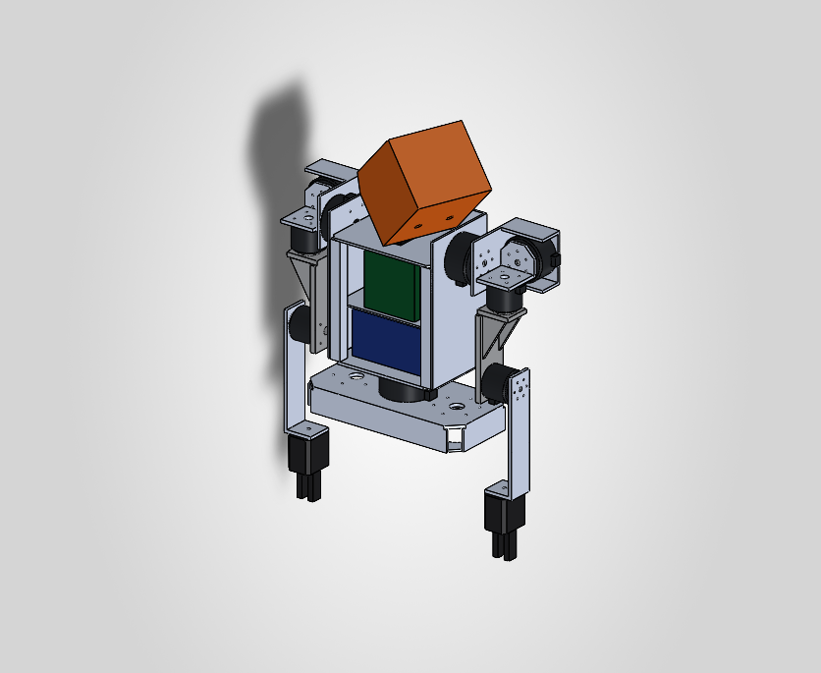
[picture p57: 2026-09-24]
verification/images/poses/JX1_UpperBody_head_left_down.png

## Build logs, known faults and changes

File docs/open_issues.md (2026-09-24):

# JX1 unresolved issues (v0.6, 2026-09-24)

Status legend: OPEN · IN PROGRESS · RESOLVED (kept for traceability).

| ID | Issue | Evidence | Next action | Blocks | Status |
|---|---|---|---|---|---|
| OI-1 | MAI bolt-circle diameters, thread sizes and pilot diameters are ASSUMED; RobStride STEP models and dimensioned outlines exist (manual §1.1, image only) | `actuators/modular_actuator_interface.md` | dimension RS00/02/03/04/06 STEP files → update `tools/cad/params.py` → rebuild CAD (fully parametric) | ordering CNC parts | OPEN |
| OI-2 | **Actuator margins at the fast gait (0.79 m/s)** with the CAD masses (33.6 kg), for the scripted ZMP gait: hip yaw 37.0 N·m raw dynamic peak vs RS06 36 N·m (needs 55.5 with the 1.5× policy); hip roll 43.1 vs RS03 60 (needs 64.6); hip pitch 80.0 vs RS04 120 (exactly at policy). **The learned controller (default `rl/policies/jx1_walk_stand_v7`, commit 31ccead) meets every hip and knee margin at 0.8 m/s on the same CAD model**: hip yaw 8.3 N·m peak (×1.5 = 12.4 ≤ 36), hip roll 32.2 (48.3 ≤ 60), hip pitch 22.5 (33.8 ≤ 120), knee 59.6 (89.4 ≤ 120), all RMS below the rated torques; ankle pitch 37.7 N·m = 82 % of the 46 N·m linkage capability (see OI-21) | `calculations/results/iter2_C_cad_masses/requirements.yaml`; `verification/mujoco_walking.json`; `rl/policies/jx1_walk_stand_v7/sim2sim.json` (per-joint peak/RMS), `docs/final_robot_specification.md` | keep the RS06 hip yaw and walk with the learned controller (command range ≤ 0.8 m/s as trained); cap the scripted ZMP gait at ≈ 0.6 m/s; bench-verify actuator torque (OI-9) | actuator order | MITIGATED (learned controller, sim) |
| OI-3 | Ankle corner (plantarflexion + inversion): rod B touches motor B housing | `verification/ankle_workspace_L.json` (162-pose SolidWorks sweep, 92 % of the box free) | coupled pitch/roll polygon in `design_point.yaml` → `joint_map.yaml` `coupled_limits`, enforced by the Jetson controller | — | RESOLVED |
| OI-4 | Structural adequacy of the structure | `calculations/results/structural/report.md` | printed PA-CF failed everywhere (legs SF 0.07–0.90, upper body 0.14–1.23 static) → 6061/7075 plate. Final CAD: hip yaw 7075 1.77/1.58, hip roll 2.76/3.80, thigh 2.31/2.78, shin 3.37/4.17, foot 3.50/2.03 (lightening hole moved off the clevis; was 1.48 fatigue), pelvis 2.90/3.44, crank 14.4/24.7, torso 4.44/3.59, shoulder pitch 2.17/1.75, shoulder roll 2.05/1.66, forearm 3.27/2.65; upper arm redesigned (10/8 mm + gussets: 5.99/4.84 on the final CAD; 6 mm failed 1.34/1.08) | bolted-joint rules (OI-17); prototype strain check | release of CNC parts | RESOLVED (design) |
| OI-5 | Part materials inside SolidWorks | `tools/cad/make_manufacturing.py` | every machined part now carries its SolidWorks library material (6061-T6 (SS), 7075-T6 (SN), AISI 1045) and linked MATERIAL/WEIGHT properties; printed parts (PA-CF, PETG-CF) have no library material; simulation keeps the documented densities | custom PA-CF/PETG-CF materials; weigh the first parts and update densities | accurate inertias | IN PROGRESS |
| OI-6 | Knee flexion limited to 120° (target ≥ 135° for get-up/kneel) | CAD verification | V2 knee-at-hip linkage study | get-up behaviours | OPEN |
| OI-7 | Leg–leg contact beyond ≈ 8° hip adduction with the other leg vertical | `verification/robot_motion_verification.json` (single_leg_overshift: 14° stance adduction + adducted swing leg → 13 contacts; single_leg_T_pose at 8° with the swing leg abducted 6° is clear) | self-collision constraint in controller/RL; consider 0.21 m hip spacing. Learned gait on the CAD hulls, default `jx1_walk_stand_v7` (`rl/policies/jx1_walk_stand_v7/envelope.json`, `envelope_rough.json`): grazing leg contact (≤ 0.8 mm hull overlap) in 5/130 (flat) and 4/130 (rough) envelope commands, mostly side-steps beyond the trained ±0.3 m/s (vy ±0.45; foot–foot for up to 14 % of steps at (+0.40, +0.45)); 1 inside the trained range: the 0.3 m/s side-step on rough ground, shins for 0.3 % of steps (0.3 mm) | one-leg balance, fast side-steps | OPEN (learned gait: grazing contact beyond the trained side-step range) |
| OI-8 | Upper body (torso, battery bay, electronics, arms, head) | `verification/upper_motion_verification.json` (36/36 exact, 36/36 collision-free), `verification/robot_motion_verification.json` (13/13 exact, 11/11 collision-free within the documented limits), FEA above | wiring routing through the joints and covers (phase 3) | — | RESOLVED (CAD, verification, FEA) |
| OI-9 | Actuator rotor inertia / phase resistance not published — armature and copper-loss values ESTIMATED | `actuators/actuator_catalog.yaml` | bench sys-ID (torque–speed, thermal, friction) | accurate sim + runtime | OPEN |
| OI-10 | Hole-pattern clocking between actuator envelopes and brackets not aligned after the connector clocking | CAD | align patterns once OI-1 values are known | drawings | OPEN |
| OI-11 | Manufacturing drawings | `manufacturing/index.md` | 24 STEP files, 14 A3 PDF drawings (views, material, process, qty, tolerance, envelope, SolidWorks mass, hole list; STEP = dimensional master), 24 PETG fit-check STLs, 3 print STLs | re-export after OI-1 | ordering | RESOLVED |
| OI-12 | CNC/laser prices ESTIMATED (no public per-part pricing in India); more CNC parts after OI-4 | `bom/master_bom.csv` | Robocon CNC / Makenica / local laser-shop quotes with the DXF/STEP set | cost accuracy | OPEN |
| OI-13 | GitHub remote `nickthelegend/thenar-jx1` does not exist and the available token cannot create repositories | `git push` → "Repository not found" | owner creates the empty private repo (or grants Administration: write) → `git push -u origin main` | publishing | OPEN (BLOCKER for push) |
| OI-14 | RobStride output-bearing load ratings (axial/radial/tilting moment) are not published; the hip-yaw RS06 carries the whole leg's pitch/roll moments as a tilting moment (up to ≈ 130 N·m in LC1, ≈ 64 N·m walking) | manual rev. 260713 (no bearing table); `calculations/results/structural/report.md` hand calcs | ask RobStride for bearing ratings; design provision for a yaw support bearing (thin-section 6816/crossed-roller between pelvis and yaw bracket) | hip-yaw release | OPEN |
| OI-15 | Mass growth from the aluminium structure changes the dynamics | `calculations/results/iter2_C_cad_masses/` (33.61 kg total, upper body 12.0 kg) | iteration-2 leg analysis done → result in OI-2; power budget: 92 W standing, 285 W walking 0.52 m/s, runtime 1.3 h walking / 4.1 h standing | — | RESOLVED (→ OI-2) |
| OI-16 | Shoulder-pitch CAD mate window limited to −115…+60° (SolidWorks angle-mate windows must lie in 0–180°); the −170° overhead range was not CAD-verified | `tools/cad/upper_kinematics.py` `CAD_WINDOW`; `verification/mujoco_arm_range.json` (`simulation/mujoco/verify_arm_range.py`, images `verification/images/mujoco/arms_overhead_{front,side}.png`) | verified in MuJoCo on the CAD collision hulls, method validated against SolidWorks: 49/49 poses agree (13 whole-robot + 36 upper-body, incl. the OI-7 and OI-18 clashes). Reach-up to −170° is clear with the arm straight at every shoulder roll (−10…150°) and with the elbow at −90°; the neck never meets a raised arm (0/1080 poses). Overhead contact only with the hand behind the head (shoulder yaw 45–90° inward with the elbow at −90…−135°) or at roll 150° + yaw 90° → arm-motion constraint, no hardware change | overhead reach | RESOLVED (MuJoCo CAD hulls; SolidWorks second limit-mate configuration optional) |
| OI-17 | Bolted plate joints (hip-roll bracket, shin, pelvis box) are modelled as monolithic in the FEA; joint slip/efficiency not analysed | FEA method note; `calculations/results/structural/plate_joint_loads.json` (`calculations/structural/plate_joint_loads.py`, loads from `leg_loads.py` at 33.61 kg) | design loads computed — hip-roll corner LC1 |M| 80/186/45 N·m (My = 120 N·m hip-pitch reaction + Fz × 68 mm), shin joggle LC1 |M| 66/100/38 N·m. Hand sizing (M5 12.9 at 70 % proof ≈ 9.6 kN preload, μ 0.2 bare 6061, Ø5 steel dowels): hip-roll corner viable with 4× M5 + 2× Ø5 dowels only if the dowels sit at the ends of the z-span ≥ 70 mm apart (2.65 kN per dowel vs ≈ 7 kN shear); bolts alone slip at LC1 but not in walking (LC2); M5 threads in the corner bar need ≥ 10 mm engagement or a helicoil. Shin joggle: 4× M5 12.9 per interface on ≈ 50×30 mm stays under slip at LC1. CNC one-piece removes both joints. Next: add the fastener/dowel geometry in CAD, then a strain check on the prototype | release of plate parts | IN PROGRESS |
| OI-18 | Arms hanging straight leave ≈ 27 mm between gripper and thigh plate; 30° hip abduction closes it | `verification/robot_motion_verification.json` (abduction_arms_down: contact, kept as a negative test; abduction_arms_relaxed with shoulder roll 8° is clear) | controller constraint (shoulder roll ≥ 8° while walking / abducting) — the MuJoCo walking posture and the RL task use 8° | — | OPEN (constraint) |
| OI-19 | Drawings and CAD come from a SolidWorks **Educational** licence: every PDF carries "For Instructional Use Only" and the licence restricts commercial use | `manufacturing/drawings/*.pdf` | fine for a personal/educational build; for commercial manufacture re-export from a commercial licence or rebuild from the STEP files in another CAD | commercial use | OPEN (owner decision) |
| OI-20 | Parallel ankle is driven as two per-motor MIT loops in the hubs, so the joint-space pitch/roll stiffness ratio is fixed by the linkage (≈ 1.27, J ≈ [[0.8, 0.9], [0.8, −0.9]]); a 60/40 joint-space PD is not realisable | `ros2_ws/src/jx1_hw` (HIL twin), `firmware/hub/jx1_hub` | RL task now uses the realisable 51.2/64.8 N·m/rad (motor kp 40, kd 1.5); optional firmware: add the coupling torques at 500 Hz for exact joint-space ankle PD | ankle control quality | OPEN (firmware option) |
| OI-21 | Ankle torque headroom: the interim RL policy's ankle pitch peaked at 87–100 % of the 46 N·m linkage capability in sim-to-sim; hub torque caps are 80 % of peak | `rl/policies/jx1_walk_rough/sim2sim.json`, `sim2sim_rough.json` | the torque-limit penalty (85 % soft limit) + rough-ground fine-tune: peaks 71 % (flat) / 73 % (rough heightfield) at 0.8 m/s, 85 % at 1.09 m/s (beyond the trained range), i.e. under the 80 % hub cap in the trained range. Default `jx1_walk_stand_v7` (`power.json`, `hw_loop_fast_check.json`): ankle pitch 82 % of the linkage capability at 0.8 m/s; uncapped, the ankle *motor* reaches 34.2 N·m = 95 % of the RS06 36 N·m peak. The hub firmware now caps the total MIT torque (not only the feed-forward term) at 80 % of peak (commit 0969357), and with the cap the hardware-in-the-loop chain still walks 0.68 m/s at a 0.8 m/s command; ankle-motor RMS current 84 % of rated at 0.8 m/s. Bench-check the ankle motors (torque and temperature) before fast walking | aggressive gaits | MITIGATED (sim) |
| OI-22 | Isaac Lab task and the Isaac Sim ROS 2 bridge have not run: no Isaac Sim on the design PC (RTX 3050 6 GB is below Isaac Sim's recommended spec) | `simulation/isaac/isaaclab/offline_check.json` (89/89 offline checks against the Isaac Lab 2.3.2, rsl_rl 3.1.2 and Isaac Sim 5.1 sources; fixed a lost ONNX normaliser, two OmniGraph target inputs set as strings, the bridge spawn pose/gains) | run on an Isaac-capable PC: `scripts/train.py`, then `scripts/export_offline.py` and `rl/sim2sim.py` on the bundle | Isaac workflow | OPEN (runtime) |
| OI-23 | Sim-to-real gaps: RobStride MIT-mode latency and torque–speed curve, joint friction, IMU noise/latency, CAN timing | `rl/latency_test.py`, `rl/policies/*/latency.json`, `ros2_ws/src/jx1_hw` (HIL twin) | modelled now: hub 20 ms target ramp, 0–15 ms sensing and 0–10 ms actuation latency, realisable ankle gains; `hw_node` forwards commands without timer delay (HIL turn tracking 62 → 73 % for the same policy). Torque–speed check added (`rl/power_test.py`, conservative linear stall-to-no-load line at 41.6 V): with `jx1_walk_stand_v7` the ankle motor reaches 1.00 at 0.8 m/s (34.2 N·m at 2.0 rad/s), every other actuator ≤ 0.46. Remaining: bench actuator system ID (OI-9) → measured torque–speed + friction model | first hardware walking | IN PROGRESS |
| OI-24 | Hip-yaw bracket tails clash when both hips toe out: first contact at 21° each (symmetric), or 11° on one side with the other at its 45° limit (MuJoCo, CoACD hulls — conservative); toe-in never clashes | MuJoCo sweep 2026-09-24 (`simulation/mujoco/jx1.xml`); learned controller: largest toe-out sum 22.9° (spinning at 0.9 rad/s, beyond its 0.6 rad/s range), 15.4° walking + turning, 6° straight at 0.8 m/s | coupled limit toe-out_L + toe-out_R ≤ 40° as a deployment guard; confirm in SolidWorks when the robot assembly is rebuilt (OI-25); shorter bracket tail or 0.21 m hip spacing in V2 | aggressive turning | OPEN (margin 17° with the learned gait) |
| OI-25 | `JX1_Robot.SLDASM` predates the upper-arm redesign: its rebuild + whole-robot re-verification was aborted to relieve system memory (commit near the 52 GB limit, C: full) | `verification/robot_motion_verification.json` (pre-redesign arms) | `build_robot_assembly.py` + `verify_robot_motion.py --images` in a fresh SolidWorks session with ≥ 12 GB commit headroom | — | OPEN |
| OI-26 | Fast-gait peak battery current ≈ 40 A (1682 W at 41.6 V, scripted ZMP gait, CAD masses) equals the JBD SP14S004 40 A BMS rating; the 13S2P 50S pack itself allows 50 A cont. | `calculations/results/iter2_C_cad_masses/power_budget.json`; learned controller: `rl/policies/jx1_walk_stand_v7/power.json` (same electrical model): 0.8 m/s 347 W mean / 663 W peak = 15.9 A at 41.6 V, 0.5 m/s 274 W | with the learned controller the peak demand is 40 % of the BMS rating; keep the 100-ms over-current delay setting for the scripted gait | fast gait | MITIGATED (learned controller, sim) |
| OI-27 | The learned policy steps in place at zero command (left sole off the floor 41 % of the time, right 20 %, ≤ 3.5 cm): standing costs 163 W (hip roll at 69 % of rated current) vs 92 W for a static stand, 2.3 h instead of 4.1 h on the pack | `rl/policies/jx1_walk_rough/power.json`, CadSim stand rollout 2026-09-24 | train a stand mode: gate the gait clock (stance for both feet) and reward zero foot lift at zero command, or switch to a static PD stand below a command threshold with a dwell. Stand-mode fine-tune `jx1_walk_stand` (walk_v5_stand, commit 4e6c1da, `rl/policies/jx1_walk_stand/REPORT.md`): stands at 79 W with 0 foot lift-offs (4.7 h on the pack vs 2.3 h), settles after walking, pushes 22.5–55.8 N·s, but its tracking regressed (envelope 98 vs 109/130, 0.3 rad/s turns 83 % vs 101 %, HIL turn 75 % vs 88 %; leftward side-steps under-track), so `jx1_walk_rough` stays the default. v6 `jx1_walk_stand_sym` (zero-command share 10 %, mirror loss 0.2; commit d91f0a0): widest envelope so far (117/130 flat and rough), symmetric side-steps (±0.36 m/s), walking pushes 29.5–57.7 N·s, no self-contact, stands at 79 W; but slow turns 80 %, HIL 88 % forward / 71 % turn, −0.03 rad/s yaw drift, and a weak standing push (11.7 N·s forward vs 33.3) because the both-feet-down contact reward penalises recovery steps. **v7 `jx1_walk_stand_v7` (commit 31ccead) is the default**: stand mode = gait clock gated below |command| 0.1, no swing or contact target when standing, no stand-mode contact reward, yaw tracking weight 0.8. It stands with 0 foot lift-offs at 73 W (5.1 h on the pack), settles within 2 s after walking, survives 26–55 N·s standing pushes and 29–60 N·s walking pushes, tracks 118/130 (flat) and 119/130 (rough) envelope commands with 0 falls and turns as well as `jx1_walk_rough` (HIL 92 %, ROS 2 99 %). Weaker: slow forward walking undershoots (HIL 84 % of 0.3 m/s, ROS 2 93 % of 0.4 m/s). v5/v6 kept as experiments | standing runtime | RESOLVED (sim) |

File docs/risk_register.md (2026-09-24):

# JX1 risk register (v0.5, 2026-09-24)

Likelihood (L) and impact (I) on a 1–5 scale; score = L × I.

| ID | Risk | L | I | Score | Mitigation | Owner / status |
|---|---|---|---|---|---|---|
| R1 | Actuator import: customs delay, duty higher than the 32.3 % assumed, courier damage | 3 | 4 | 12 | order one of each class first for bench tests; China-distributor quote in parallel; 2 spares of RS04/RS06 | Procurement / OPEN |
| R2 | Hip-yaw (and hip-roll) torque margin at the fast gait: CAD-mass iteration 2 gives 37.0 N·m raw hip-yaw peak at 0.79 m/s vs RS06 36 N·m; nominal 0.52 m/s needs 20.8 | 4 | 3 | 12 | cap walking speed ≈ 0.6 m/s with the current actuators, or RS03 hip yaw (+0.26 kg/leg); RL torque-limit penalty; mass reduction | Design / MITIGATED in sim (OI-2: the default learned controller stays within the hip/knee margins at 0.8 m/s; scripted gait capped ≈ 0.6 m/s) |
| R3 | Printed PA-CF brackets fail under RS04-class loads | 5 | 4 | — | **materialised in analysis** (FEA SF 0.07–0.89): primary leg load path redesigned in 6061/7075 plate; printed parts kept only for low-load items (neck bracket, head, gripper, covers) | Design / MITIGATED (design); residual → R20 |
| R4 | MAI bolt patterns ASSUMED — parts won't bolt to real RobStride housings | 4 | 3 | 12 | dimension vendor STEP files before release; everything is parametric (`tools/cad/params.py`) | Design / OPEN (OI-1) |
| R5 | Knee range 120° limits get-up / kneeling behaviours | 3 | 2 | 6 | V2: knee actuator on the thigh top with push-rod | V2 |
| R6 | Ankle corner (plantarflexion + inversion): rod B touches motor B | 2 | 2 | 4 | CAD-derived coupled pitch/roll limit polygon in `joint_map.yaml`, enforced by the controller | Controls / MITIGATED (OI-3) |
| R7 | Jetson Nano software end-of-life (Ubuntu 18.04, JetPack 4.6.6 final, no CAN) | 4 | 2 | 8 | USB CAN hubs isolate the computer; ROS 2 in container; Orin Nano drop-in upgrade (₹50k) | Architecture / MITIGATED |
| R8 | Classic CAN bandwidth for 21 joints at 500 Hz | 2 | 3 | 6 | 6 buses (≤ 3 leg joints per bus → 45 % load) | Architecture / MITIGATED |
| R9 | Sim-to-real gap (masses, friction, backlash, actuator curves unmeasured) | 4 | 3 | 12 | bench sys-ID of each actuator class; weigh parts; update URDF/MJCF from measurements | Test / OPEN |
| R10 | Li-ion pack (468 Wh) fire during charge/fall | 2 | 5 | 10 | smart BMS, 58 V fuses, pack enclosure + FR liner, charge outside robot, no unattended charging | Safety / DESIGNED |
| R11 | Falls during bring-up destroy actuators/structure | 4 | 4 | 16 | gantry + harness for all early tests; soft covers on knees/hips; fall-detection damping | Test / PLANNED |
| R12 | Leg–leg self-collision: adduction > ≈ 8° (OI-7); both hips toed out > 21° each clash the hip-yaw brackets (OI-24) | 3 | 2 | 6 | controller/RL self-collision constraints (stance adduction ≤ 8°, toe-out sum ≤ 40°); collision hulls in sim | Controls / OPEN |
| R13 | Cost overrun — actuators are ≈ 77 % of the BOM; CNC/laser prices unquoted | 3 | 3 | 9 | China-distributor route (−₹1.87 lakh); quotes with the STEP/PDF set; V2 DIY actuator localisation | Cost / OPEN |
| R14 | Thermal: RS04 rated torque assumes a large Al heat sink | 2 | 3 | 6 | aluminium thigh/shin/hip brackets now sink heat; thermal monitoring; RMS utilisation ≤ 61 % in analysis | Design / MITIGATED |
| R15 | Single supplier (RobStride) for all 21 joints | 2 | 4 | 8 | MAI envelopes accept Damiao / SteadyWin alternatives; protocol abstraction in hub firmware | Architecture / MITIGATED |
| R16 | Walking performance unproven on hardware | 4 | 3 | 12 | done in sim: MuJoCo ZMP walking on the CAD model (4/4 gaits, push 5.3–7.8 N·s); learned controller `jx1_walk_stand_v7` (default) on the CAD model: 8/8 scenarios on flat and rough ground, 0.8 m/s with hips and knees within the 1.5× peak policy (ankle motors at the 80 % hub cap, OI-21), pushes 29–60 N·s walking / 26–55 N·s standing, stands still at 73 W, over ROS 2 (3 start paths incl. ros2_control) and through the hub-firmware twin (HIL, 84 % / 92 % forward / turn tracking at 0.3; 0.68 m/s at 0.8 m/s); next: gantry tests (`docs/build_guide.md`, `ros2_ws/src/jx1_hw/README.md`) | Sim / MITIGATED in sim, OPEN on hardware |
| R17 | RobStride output-bearing tilting-moment capacity unpublished; hip-yaw RS06 carries the leg's pitch/roll moments | 3 | 4 | 12 | request ratings from RobStride; provision a yaw support bearing (pelvis ↔ yaw bracket) | Design / OPEN (OI-14) |
| R18 | Mass growth (aluminium structure, real upper body) erodes actuator margins (hip yaw, hip roll, ankle) | 4 | 3 | 12 | CAD-mass iteration-2 analysis (OI-15); lightening pockets in the 7075/6061 parts; RS03 hip-yaw option | Design / OPEN |
| R19 | Arm–thigh contact with arms hanging straight during hip abduction | 3 | 2 | 6 | shoulder-roll ≥ 8° posture while walking (controller constraint) or wider shoulders | Controls / OPEN (OI-18) |
| R20 | Bolted aluminium plate joints slip or loosen (FEA assumes monolithic parts) | 3 | 3 | 9 | dowel pins at every plate joint, 12.9 bolts at 70 % proof preload with thread-locker, retorque after first hours | Design / IN PROGRESS (OI-17: joint design loads + M5 12.9 / end-dowel sizing done; CAD fastener geometry + prototype strain check to go) |
| R21 | Drawings/CAD produced with a SolidWorks Educational licence ("For Instructional Use Only"): commercial manufacture or sale may breach the licence | 3 | 2 | 6 | personal/educational build is fine; for commercial use re-export from a commercial licence or rebuild from the STEP files | Owner / OPEN (OI-19) |
| R22 | Design workstation resources: SolidWorks + RL training on the same PC exhausted commit memory and C: (pagefile) during this session | 3 | 2 | 6 | one heavy job at a time, SolidWorks recycled between steps, memory guard in the job scripts; RL on an Isaac-capable PC (OI-22) | Tooling / MITIGATED |

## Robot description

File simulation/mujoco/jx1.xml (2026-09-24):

<mujoco model="jx1">
  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
  <compiler angle="radian" meshdir="../../ros2_ws/src/jx1_description/meshes" autolimits="true"/>
  <option timestep="0.002" integrator="implicitfast" cone="elliptic" impratio="10"/>
  <default>
    <joint damping="0.05" frictionloss="0.3"/>
    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
    <default class="visual">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</default>
    <default class="collision">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</default>
  </default>
  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
  <worldbody>
    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
    <light pos="0 0 3" dir="0 0 -1" directional="true"/>
    <body name="pelvis" pos="0 0 0.64">
      <freejoint name="root"/>
      <inertial pos="-0.000197 0.000099 0.122770" mass="2.97711" fullinertia="2.378231e-02 5.679341e-03 2.631614e-02 -5.483974e-08 1.387359e-07 -6.367113e-06"/>
      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
      <body name="left_hip_yaw_link" pos="0.0 0.1 0.0">
        <joint name="left_hip_yaw_joint" axis="0 0 1" range="-0.698132 0.785398" armature="0.01"/>
        <inertial pos="-0.095401 0.000208 0.028293" mass="1.74236" fullinertia="4.293323e-03 6.734537e-03 4.823527e-03 9.771242e-06 -1.827219e-03 1.002076e-05"/>
        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
        <body name="left_hip_roll_link" pos="0.0 0.0 0.0">
          <joint name="left_hip_roll_joint" axis="1 0 0" range="-0.436332 0.785398" armature="0.02"/>
          <inertial pos="-0.012467 -0.001518 0.000179" mass="1.81406" fullinertia="2.100094e-03 4.210680e-03 3.257734e-03 -5.924510e-05 1.911956e-05 -1.639369e-07"/>
          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
          <body name="left_thigh_link" pos="0.0 0.0 0.0">
            <joint name="left_hip_pitch_joint" axis="0 1 0" range="-2.007129 0.610865" armature="0.04"/>
            <inertial pos="-0.000265 0.023735 -0.198948" mass="2.33132" fullinertia="2.706574e-02 2.812478e-02 2.448940e-03 1.356276e-06 -4.296204e-05 -2.120446e-03"/>
            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
            <body name="left_shin_link" pos="0.0 0.0 -0.27">
              <joint name="left_knee_joint" axis="0 1 0" range="0.0 2.094395" armature="0.04"/>
              <inertial pos="-0.003171 -0.005267 -0.138096" mass="2.95956" fullinertia="2.277717e-02 2.184534e-02 4.271542e-03 1.230183e-04 -6.437915e-04 -2.122946e-04"/>
              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
              <body name="left_ankle_cross_link" pos="0.0 0.0 -0.3">
                <joint name="left_ankle_pitch_joint" axis="0 1 0" range="-0.959931 0.523599" armature="0.02"/>
                <inertial pos="0.000000 0.000000 -0.000000" mass="0.20234" fullinertia="3.039726e-05 2.933160e-05 3.563152e-05 -3.716382e-11 6.318937e-11 -6.720238e-11"/>
                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
                <body name="left_foot_link" pos="0.0 0.0 0.0">
                  <joint name="left_ankle_roll_joint" axis="1 0 0" range="-0.349066 0.349066" armature="0.016"/>
                  <inertial pos="0.018825 -0.000000 -0.040982" mass="0.52261" fullinertia="4.509548e-04 1.683929e-03 1.989783e-03 1.112306e-20 8.401284e-05 -5.025651e-20"/>
                  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
                </body>
              </body>
            </body>
          </body>
        </body>
      </body>
      <body name="right_hip_yaw_link" pos="0.0 -0.1 0.0">
        <joint name="right_hip_yaw_joint" axis="0 0 1" range="-0.785398 0.698132" armature="0.01"/>
        <inertial pos="-0.095401 0.000208 0.028293" mass="1.74236" fullinertia="4.293323e-03 6.734537e-03 4.823527e-03 9.771242e-06 -1.827219e-03 1.002076e-05"/>
        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
        <body name="right_hip_roll_link" pos="0.0 0.0 0.0">
          <joint name="right_hip_roll_joint" axis="1 0 0" range="-0.785398 0.436332" armature="0.02"/>
          <inertial pos="-0.012467 0.001518 0.000179" mass="1.81406" fullinertia="2.100094e-03 4.210680e-03 3.257735e-03 5.923710e-05 1.912416e-05 1.683638e-07"/>
          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
          <body name="right_thigh_link" pos="0.0 0.0 0.0">
            <joint name="right_hip_pitch_joint" axis="0 1 0" range="-2.007129 0.610865" armature="0.04"/>
            <inertial pos="-0.000264 -0.023735 -0.198948" mass="2.33132" fullinertia="2.706591e-02 2.812496e-02 2.448940e-03 -1.352274e-06 -4.304899e-05 2.120453e-03"/>
            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
            <body name="right_shin_link" pos="0.0 0.0 -0.27">
              <joint name="right_knee_joint" axis="0 1 0" range="0.0 2.094395" armature="0.04"/>
              <inertial pos="-0.003171 0.005267 -0.138096" mass="2.95956" fullinertia="2.277689e-02 2.184507e-02 4.271544e-03 -1.230232e-04 -6.438454e-04 2.122629e-04"/>
              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
              <body name="right_ankle_cross_link" pos="0.0 0.0 -0.3">
                <joint name="right_ankle_pitch_joint" axis="0 1 0" range="-0.959931 0.523599" armature="0.02"/>
                <inertial pos="0.000000 0.000000 -0.000000" mass="0.20234" fullinertia="3.039726e-05 2.933160e-05 3.563152e-05 -3.716382e-11 6.318937e-11 -6.720238e-11"/>
                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
                <body name="right_foot_link" pos="0.0 0.0 0.0">
                  <joint name="right_ankle_roll_joint" axis="1 0 0" range="-0.349066 0.349066" armature="0.016"/>
                  <inertial pos="0.018825 -0.000000 -0.040982" mass="0.52261" fullinertia="4.509548e-04 1.683929e-03 1.989783e-03 -8.132122e-21 8.401284e-05 -1.609431e-20"/>
                  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
                </body>
              </body>
            </body>
          </body>
        </body>
      </body>
      <body name="torso_link" pos="0.0 0.0 0.186">
        <joint name="waist_yaw_joint" axis="0 0 1" range="-1.570796 1.570796" armature="0.01"/>
        <inertial pos="-0.007050 0.000847 0.108772" mass="6.25958" fullinertia="6.741215e-02 4.456064e-02 4.099875e-02 2.597054e-04 2.666116e-03 -4.290095e-04"/>
        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
        <body name="left_shoulder_pitch_link" pos="0.0 0.15 0.214">
          <joint name="left_shoulder_pitch_joint" axis="0 1 0" range="-2.96706 1.047198" armature="0.0035"/>
          <inertial pos="-0.056397 0.033003 0.000000" mass="0.73250" fullinertia="1.014124e-03 1.139662e-03 1.172409e-03 3.135248e-04 2.393081e-09 -3.906123e-09"/>
          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
          <body name="left_shoulder_roll_link" pos="0.0 0.045 0.0">
            <joint name="left_shoulder_roll_joint" axis="1 0 0" range="-0.174533 2.617994" armature="0.0035"/>
            <inertial pos="-0.010114 0.000266 -0.027353" mass="0.44557" fullinertia="3.210183e-04 4.227942e-04 3.108619e-04 -1.184224e-06 1.203530e-04 -2.730350e-07"/>
            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
            <body name="left_upper_arm_link" pos="0.0 0.0 -0.07">
              <joint name="left_shoulder_yaw_joint" axis="0 0 1" range="-1.570796 1.570796" armature="0.002"/>
              <inertial pos="-0.000000 -0.013529 -0.084500" mass="0.68548" fullinertia="2.170743e-03 2.149541e-03 3.601782e-04 3.979820e-09 -8.919648e-09 2.633738e-05"/>
              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
              <body name="left_forearm_link" pos="0.0 0.0 -0.13">
                <joint name="left_elbow_joint" axis="0 1 0" range="-2.356194 0.087266" armature="0.002"/>
                <inertial pos="-0.000000 0.011680 -0.152591" mass="0.51771" fullinertia="4.097151e-03 4.068378e-03 2.425179e-04 4.614557e-11 7.951144e-10 -4.962428e-04"/>
                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
              </body>
            </body>
          </body>
        </body>
        <body name="right_shoulder_pitch_link" pos="0.0 -0.15 0.214">
          <joint name="right_shoulder_pitch_joint" axis="0 1 0" range="-2.96706 1.047198" armature="0.0035"/>
          <inertial pos="-0.056397 -0.033003 -0.000000" mass="0.73250" fullinertia="1.014125e-03 1.139669e-03 1.172416e-03 -3.135277e-04 1.444928e-09 -1.768278e-09"/>
          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
          <body name="right_shoulder_roll_link" pos="0.0 -0.045 0.0">
            <joint name="right_shoulder_roll_joint" axis="1 0 0" range="-2.617994 0.174533" armature="0.0035"/>
            <inertial pos="-0.010115 -0.000266 -0.027353" mass="0.44557" fullinertia="3.210201e-04 4.227862e-04 3.108521e-04 1.179777e-06 1.203453e-04 2.755868e-07"/>
            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
            <body name="right_upper_arm_link" pos="0.0 0.0 -0.07">
              <joint name="right_shoulder_yaw_joint" axis="0 0 1" range="-1.570796 1.570796" armature="0.002"/>
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

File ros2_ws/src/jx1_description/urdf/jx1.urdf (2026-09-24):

<?xml version="1.0"?>
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
<robot name="jx1">
  <link name="pelvis">
    <inertial>
      <origin xyz="-0.000197 0.000099 0.122770" rpy="0 0 0"/>
      <mass value="2.97711"/>
      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
    </inertial>
    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
  </link>
  <link name="left_hip_yaw_link">
    <inertial>
      <origin xyz="-0.095401 0.000208 0.028293" rpy="0 0 0"/>
      <mass value="1.74236"/>
      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
    </inertial>
    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
  </link>
  <link name="left_hip_roll_link">
    <inertial>
      <origin xyz="-0.012467 -0.001518 0.000179" rpy="0 0 0"/>
      <mass value="1.81406"/>
      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
    </inertial>
    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
  </link>
  <link name="left_thigh_link">
    <inertial>
      <origin xyz="-0.000265 0.023735 -0.198948" rpy="0 0 0"/>
      <mass value="2.33132"/>
      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
    </inertial>
    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
  </link>
  <link name="left_shin_link">
    <inertial>
      <origin xyz="-0.003171 -0.005267 -0.138096" rpy="0 0 0"/>
      <mass value="2.95956"/>
      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
    </inertial>
    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
  </link>
  <link name="left_ankle_cross_link">
    <inertial>
      <origin xyz="0.000000 0.000000 -0.000000" rpy="0 0 0"/>
      <mass value="0.20234"/>
      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
    </inertial>
    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
  </link>
  <link name="left_foot_link">
    <inertial>
      <origin xyz="0.018825 -0.000000 -0.040982" rpy="0 0 0"/>
      <mass value="0.52261"/>
      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
    </inertial>
    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
  </link>
  <link name="right_hip_yaw_link">
    <inertial>
      <origin xyz="-0.095401 0.000208 0.028293" rpy="0 0 0"/>
      <mass value="1.74236"/>
      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
    </inertial>
    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
  </link>
  <link name="right_hip_roll_link">
    <inertial>
      <origin xyz="-0.012467 0.001518 0.000179" rpy="0 0 0"/>
      <mass value="1.81406"/>
      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
    </inertial>
    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
  </link>
  <link name="right_thigh_link">
    <inertial>
      <origin xyz="-0.000264 -0.023735 -0.198948" rpy="0 0 0"/>
      <mass value="2.33132"/>
      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
    </inertial>
    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
  </link>
  <link name="right_shin_link">
    <inertial>
      <origin xyz="-0.003171 0.005267 -0.138096" rpy="0 0 0"/>
      <mass value="2.95956"/>
      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
    </inertial>
    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
  </link>
  <link name="right_ankle_cross_link">
    <inertial>
      <origin xyz="0.000000 0.000000 -0.000000" rpy="0 0 0"/>
      <mass value="0.20234"/>
      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
    </inertial>
    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
  </link>
  <link name="right_foot_link">
    <inertial>
      <origin xyz="0.018825 -0.000000 -0.040982" rpy="0 0 0"/>
      <mass value="0.52261"/>
      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
    </inertial>
    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
  </link>
  <link name="torso_link">
    <inertial>
      <origin xyz="-0.007050 0.000847 0.108772" rpy="0 0 0"/>
      <mass value="6.25958"/>
      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
    </inertial>
    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
  </link>
  <link name="left_shoulder_pitch_link">
    <inertial>
      <origin xyz="-0.056397 0.033003 0.000000" rpy="0 0 0"/>
      <mass value="0.73250"/>
      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
    </inertial>
    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
  </link>
  <link name="left_shoulder_roll_link">
    <inertial>
      <origin xyz="-0.010114 0.000266 -0.027353" rpy="0 0 0"/>
      <mass value="0.44557"/>
      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
    </inertial>
    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
  </link>
  <link name="left_upper_arm_link">
    <inertial>
      <origin xyz="-0.000000 -0.013529 -0.084500" rpy="0 0 0"/>
      <mass value="0.68548"/>
      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
    </inertial>
    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
  </link>
  <link name="left_forearm_link">
    <inertial>
      <origin xyz="-0.000000 0.011680 -0.152591" rpy="0 0 0"/>
      <mass value="0.51771"/>
      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
    </inertial>
    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
  </link>
  <link name="right_shoulder_pitch_link">
    <inertial>
      <origin xyz="-0.056397 -0.033003 -0.000000" rpy="0 0 0"/>
      <mass value="0.73250"/>
      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
    </inertial>
    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
  </link>
  <link name="right_shoulder_roll_link">
    <inertial>
      <origin xyz="-0.010115 -0.000266 -0.027353" rpy="0 0 0"/>
      <mass value="0.44557"/>
      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
    </inertial>
    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
  </link>
  <link name="right_upper_arm_link">
    <inertial>
      <origin xyz="-0.000000 0.013529 -0.084150" rpy="0 0 0"/>
      <mass value="0.68548"/>
      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
    </inertial>
    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
  </link>
  <link name="right_forearm_link">
    <inertial>
      <origin xyz="0.000000 -0.011680 -0.152591" rpy="0 0 0"/>
      <mass value="0.51771"/>
      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
    </inertial>
    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
  </link>
  <link name="neck_link">
    <inertial>
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

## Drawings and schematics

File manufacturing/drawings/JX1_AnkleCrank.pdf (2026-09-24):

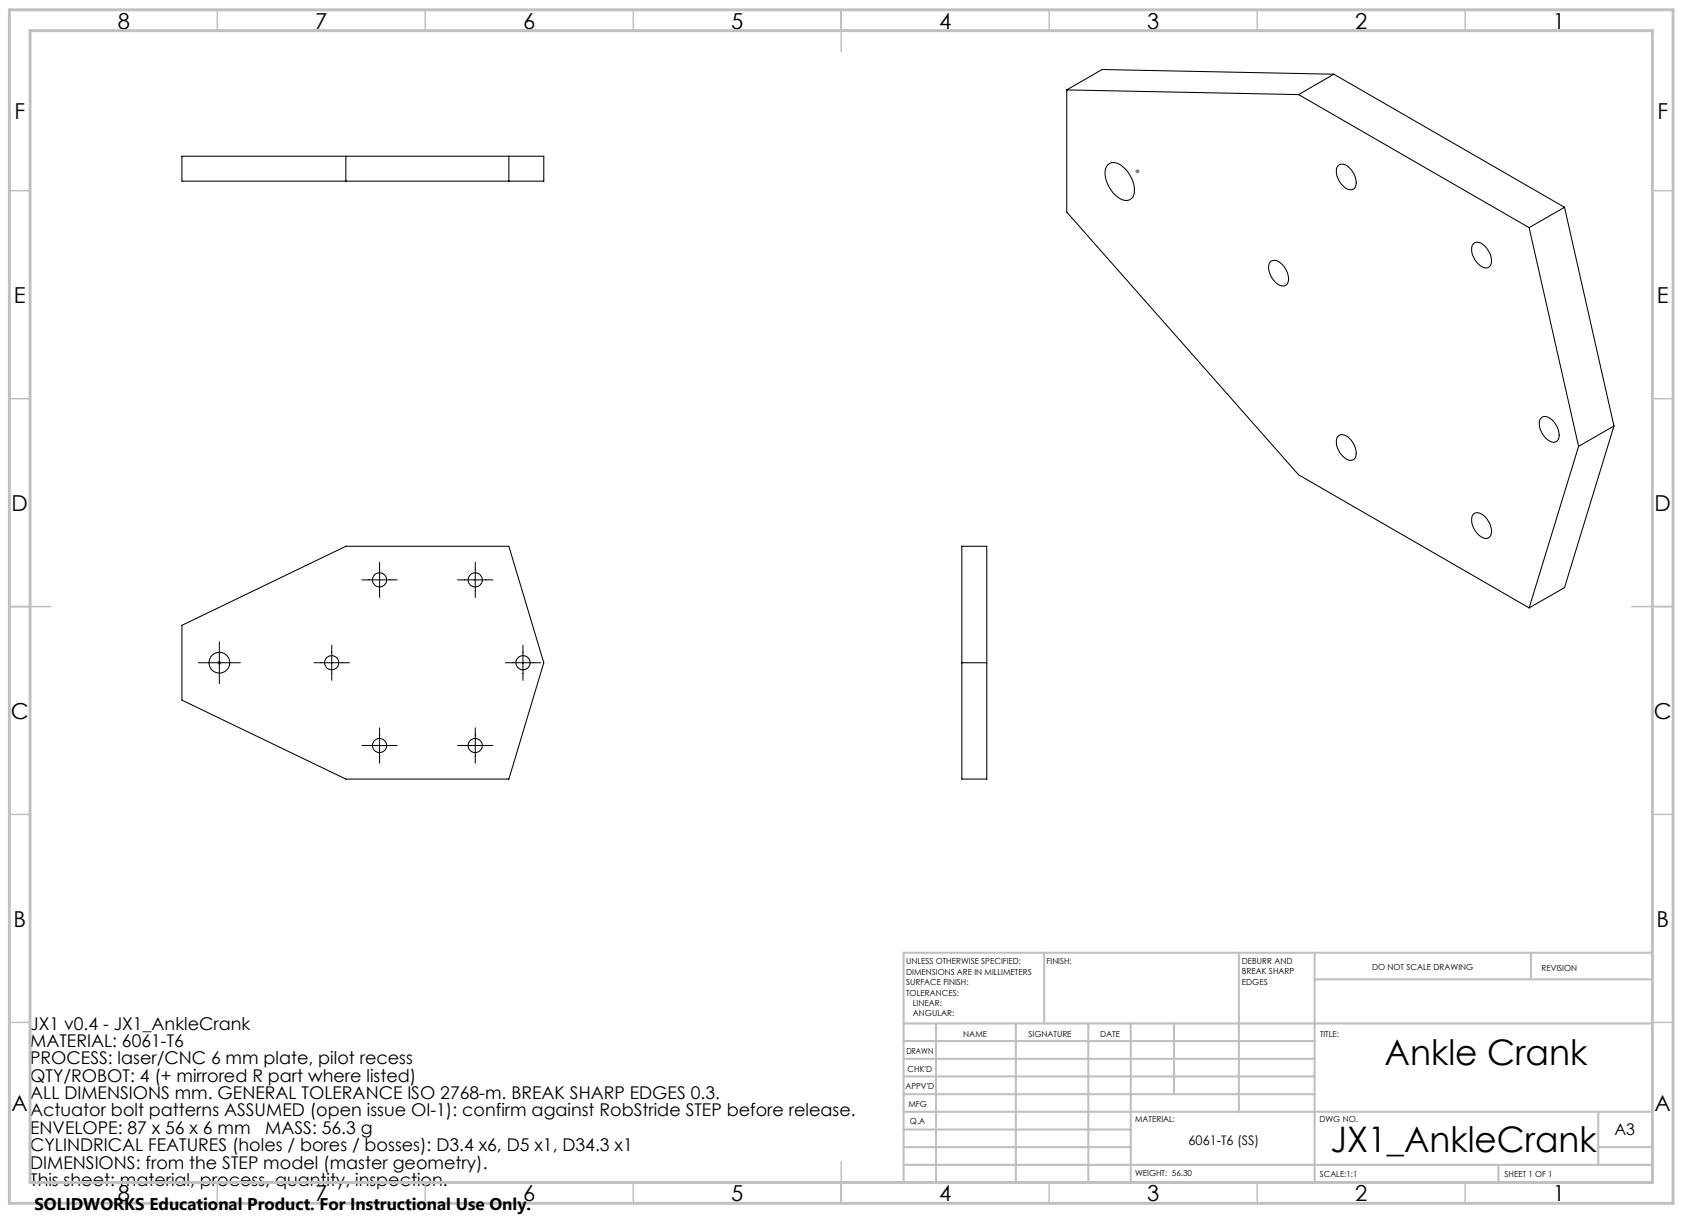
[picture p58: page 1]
FINISH:; DEBURR AND; BREAK SHARP; DO NOT SCALE DRAWING; REVISION; SCALE:1:1; SHEET 1 OF 1; WEIGHT: 56.30

UNLESS OTHERWISE SPECIFIED:
DIMENSIONS ARE IN MILLIMETERS
SURFACE FINISH:
TOLERANCES:
LINEAR:
ANGULAR:

JX1 v0.4 - JX1_AnkleCrank
MATERIAL: 6061-T6
PROCESS: laser/CNC 6 mm plate, pilot recess
QTY/ROBOT: 4 (+ mirrored R part where listed)
ALL DIMENSIONS mm. GENERAL TOLERANCE ISO 2768-m. BREAK SHARP EDGES 0.3.
Actuator bolt patterns ASSUMED (open issue OI-1): confirm against RobStride STEP before release.
ENVELOPE: 87 x 56 x 6 mm MASS: 56.3 g
CYLINDRICAL FEATURES (holes / bores / bosses): D3.4 x6, D5 x1, D34.3 x1
DIMENSIONS: from the STEP model (master geometry).
This sheet: material, process, quantity, inspection.
SOLIDWORKS Educational Product. For Instructional Use Only.

NAME | SIGNATURE | DATE | | | | TITLE: Ankle Crank

DRAWN
CHK'D
APPV'D
MFG
Q.A | | | | MATERIAL: | DWG NO. JX1_AnkleCrank | A3 6061-T6 (SS)

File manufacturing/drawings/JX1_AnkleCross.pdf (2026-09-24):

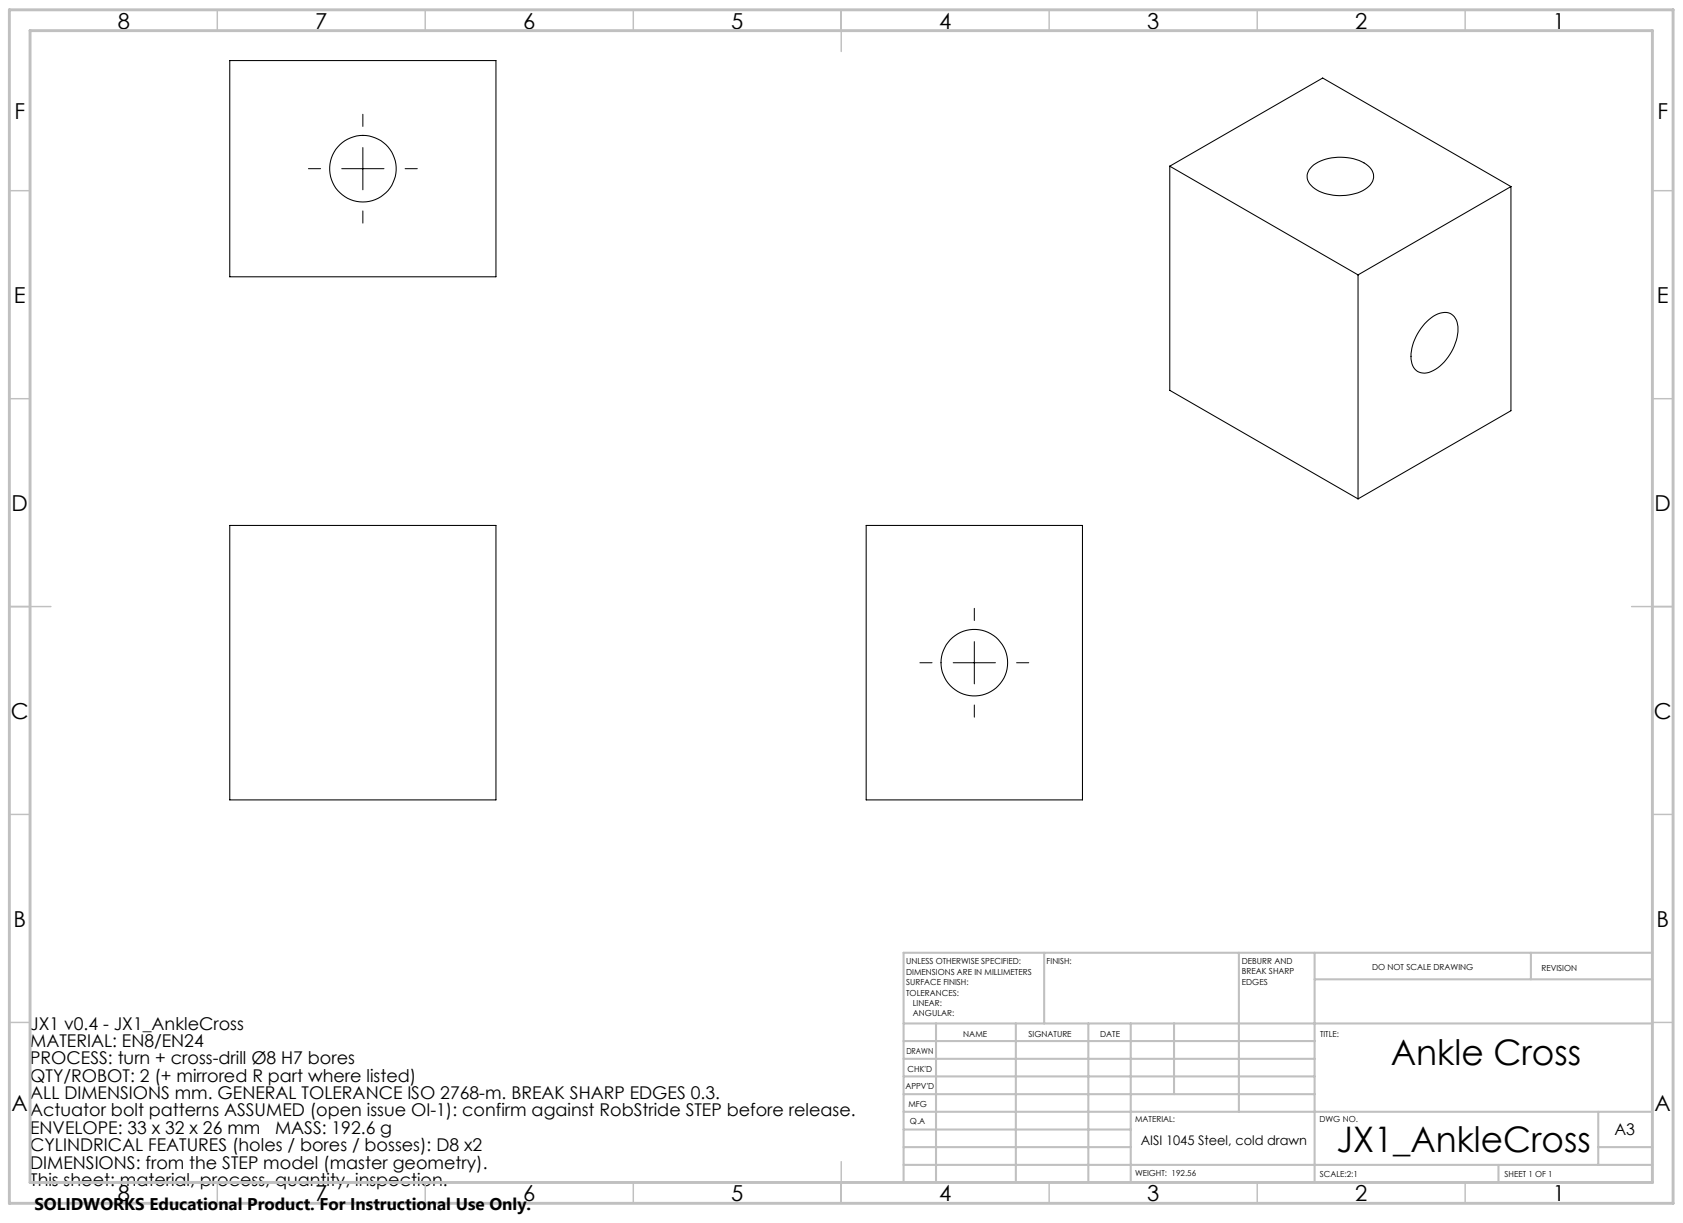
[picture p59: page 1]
FINISH:; DEBURR AND; BREAK SHARP; DO NOT SCALE DRAWING; REVISION; SCALE:2:1; SHEET 1 OF 1; WEIGHT: 192.56

UNLESS OTHERWISE SPECIFIED:
DIMENSIONS ARE IN MILLIMETERS
SURFACE FINISH:
TOLERANCES:
LINEAR:
ANGULAR:

JX1 v0.4 - JX1_AnkleCross
MATERIAL: EN8/EN24
PROCESS: turn + cross-drill Ø8 H7 bores
QTY/ROBOT: 2 (+ mirrored R part where listed)
ALL DIMENSIONS mm. GENERAL TOLERANCE ISO 2768-m. BREAK SHARP EDGES 0.3.
Actuator bolt patterns ASSUMED (open issue OI-1): confirm against RobStride STEP before release.
ENVELOPE: 33 x 32 x 26 mm MASS: 192.6 g
CYLINDRICAL FEATURES (holes / bores / bosses): D8 x2
DIMENSIONS: from the STEP model (master geometry).
This sheet: material, process, quantity, inspection.
SOLIDWORKS Educational Product. For Instructional Use Only.

NAME | SIGNATURE | DATE | | | | TITLE: Ankle Cross

DRAWN
CHK'D
APPV'D
MFG
Q.A | | | | MATERIAL: | DWG NO. JX1_AnkleCross | A3 AISI 1045 Steel, cold drawn

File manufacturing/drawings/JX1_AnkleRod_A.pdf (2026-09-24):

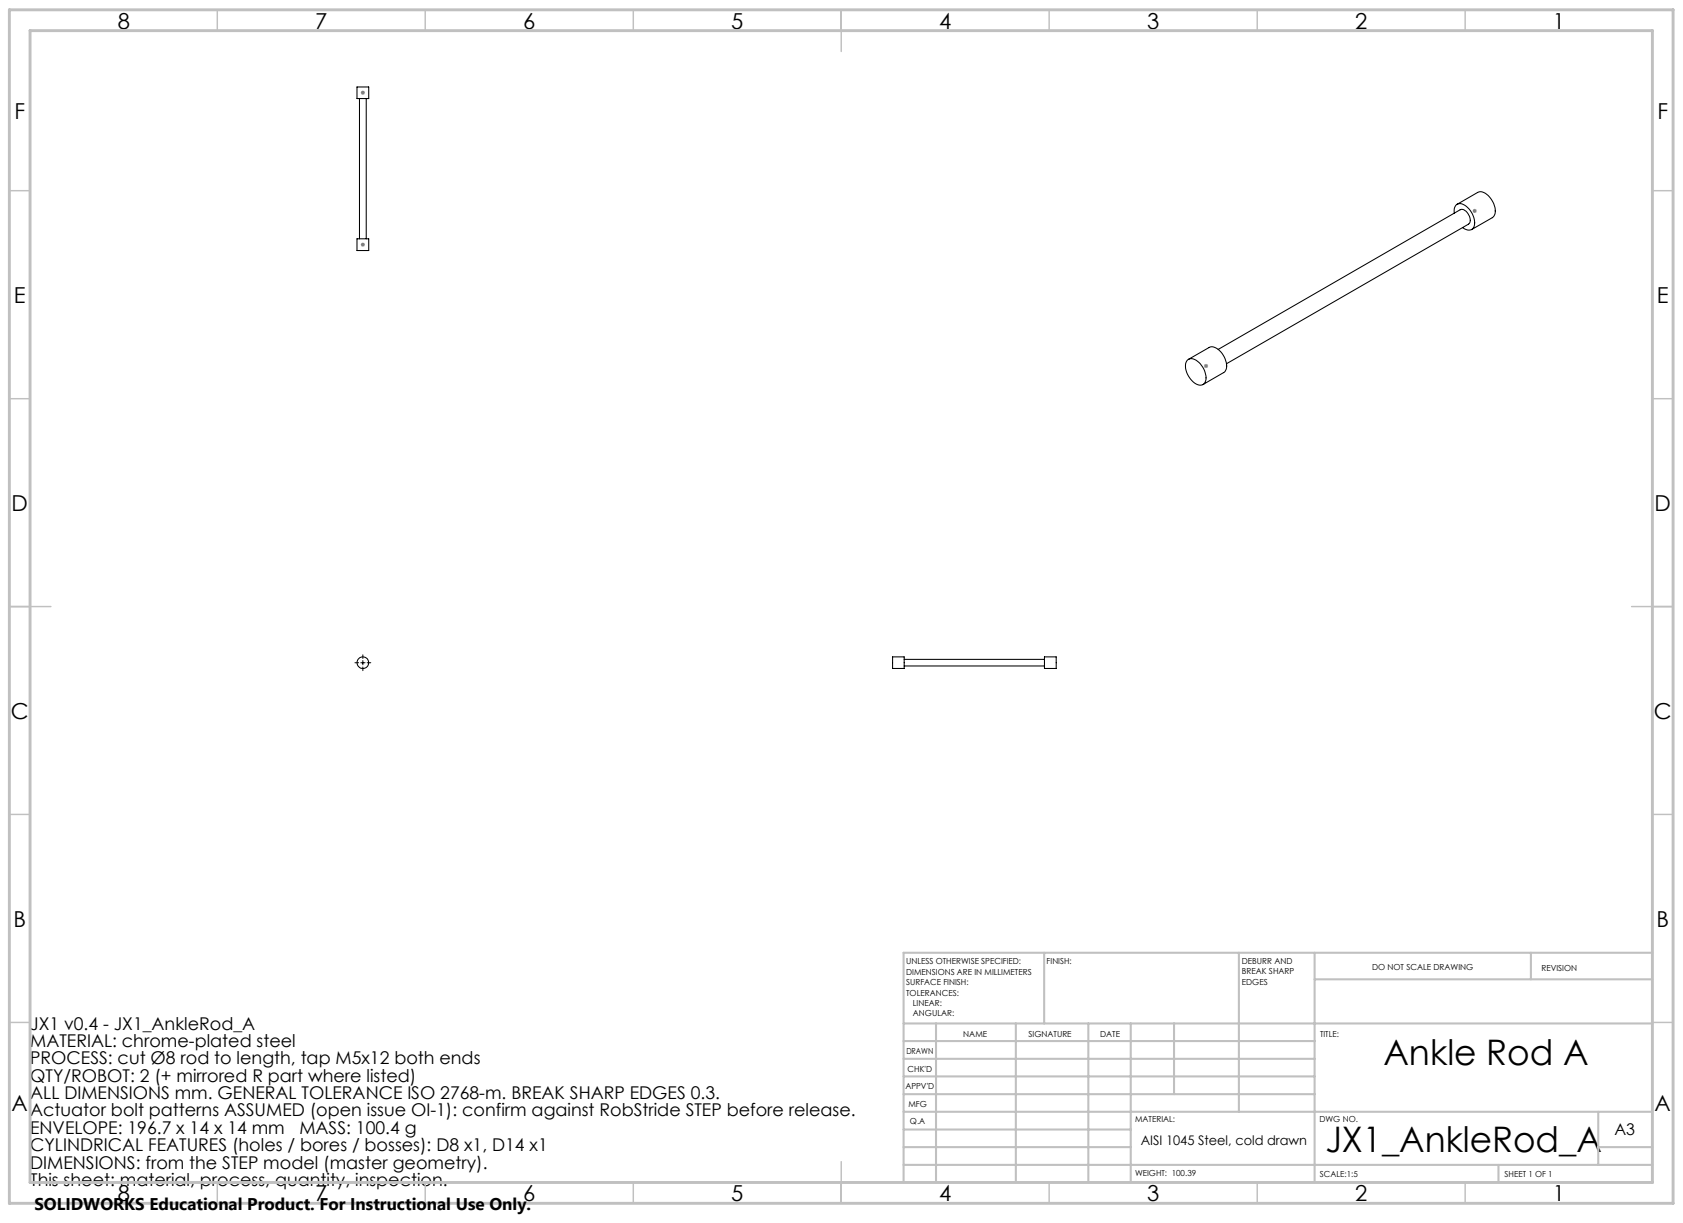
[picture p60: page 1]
FINISH:; DEBURR AND; BREAK SHARP; DO NOT SCALE DRAWING; REVISION; SCALE:1:5; SHEET 1 OF 1; WEIGHT: 100.39

UNLESS OTHERWISE SPECIFIED:
DIMENSIONS ARE IN MILLIMETERS
SURFACE FINISH:
TOLERANCES:
LINEAR:
ANGULAR:

JX1 v0.4 - JX1_AnkleRod_A
MATERIAL: chrome-plated steel
PROCESS: cut Ø8 rod to length, tap M5x12 both ends
QTY/ROBOT: 2 (+ mirrored R part where listed)
ALL DIMENSIONS mm. GENERAL TOLERANCE ISO 2768-m. BREAK SHARP EDGES 0.3.
Actuator bolt patterns ASSUMED (open issue OI-1): confirm against RobStride STEP before release.
ENVELOPE: 196.7 x 14 x 14 mm MASS: 100.4 g
CYLINDRICAL FEATURES (holes / bores / bosses): D8 x1, D14 x1
DIMENSIONS: from the STEP model (master geometry).
This sheet: material, process, quantity, inspection.
SOLIDWORKS Educational Product. For Instructional Use Only.

NAME | SIGNATURE | DATE | | | | TITLE: Ankle Rod A

DRAWN
CHK'D
APPV'D
MFG
Q.A | | | | MATERIAL: | DWG NO. JX1_AnkleRod_A | A3 AISI 1045 Steel, cold drawn

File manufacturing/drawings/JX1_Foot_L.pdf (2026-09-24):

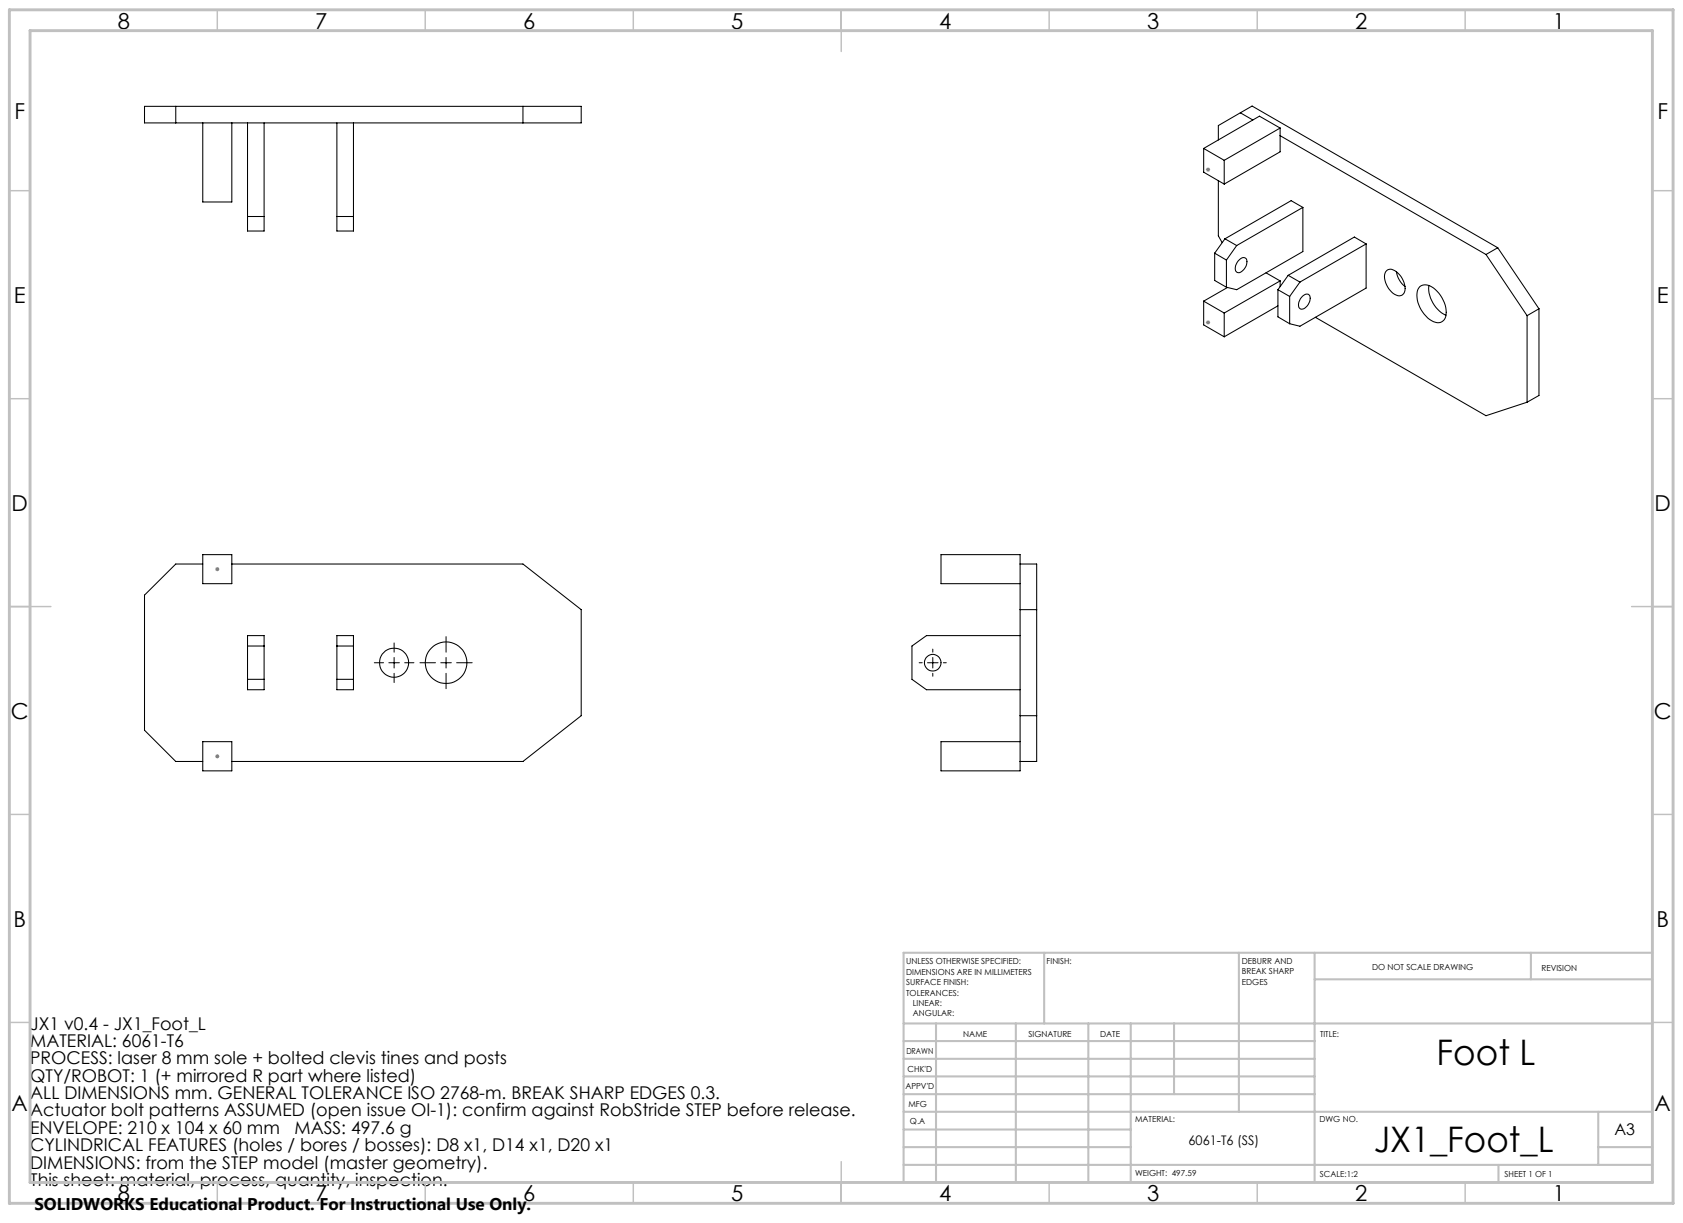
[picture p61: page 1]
FINISH:; DEBURR AND; BREAK SHARP; DO NOT SCALE DRAWING; REVISION; SCALE:1:2; SHEET 1 OF 1; WEIGHT: 497.59

UNLESS OTHERWISE SPECIFIED:
DIMENSIONS ARE IN MILLIMETERS
SURFACE FINISH:
TOLERANCES:
LINEAR:
ANGULAR:

JX1 v0.4 - JX1_Foot_L
MATERIAL: 6061-T6
PROCESS: laser 8 mm sole + bolted clevis tines and posts
QTY/ROBOT: 1 (+ mirrored R part where listed)
ALL DIMENSIONS mm. GENERAL TOLERANCE ISO 2768-m. BREAK SHARP EDGES 0.3.
Actuator bolt patterns ASSUMED (open issue OI-1): confirm against RobStride STEP before release.
ENVELOPE: 210 x 104 x 60 mm MASS: 497.6 g
CYLINDRICAL FEATURES (holes / bores / bosses): D8 x1, D14 x1, D20 x1
DIMENSIONS: from the STEP model (master geometry).
This sheet: material, process, quantity, inspection.
SOLIDWORKS Educational Product. For Instructional Use Only.

NAME | SIGNATURE | DATE | | | | TITLE: Foot L

DRAWN
CHK'D
APPV'D
MFG
Q.A | | | | MATERIAL: | DWG NO. JX1_Foot_L | A3 6061-T6 (SS)

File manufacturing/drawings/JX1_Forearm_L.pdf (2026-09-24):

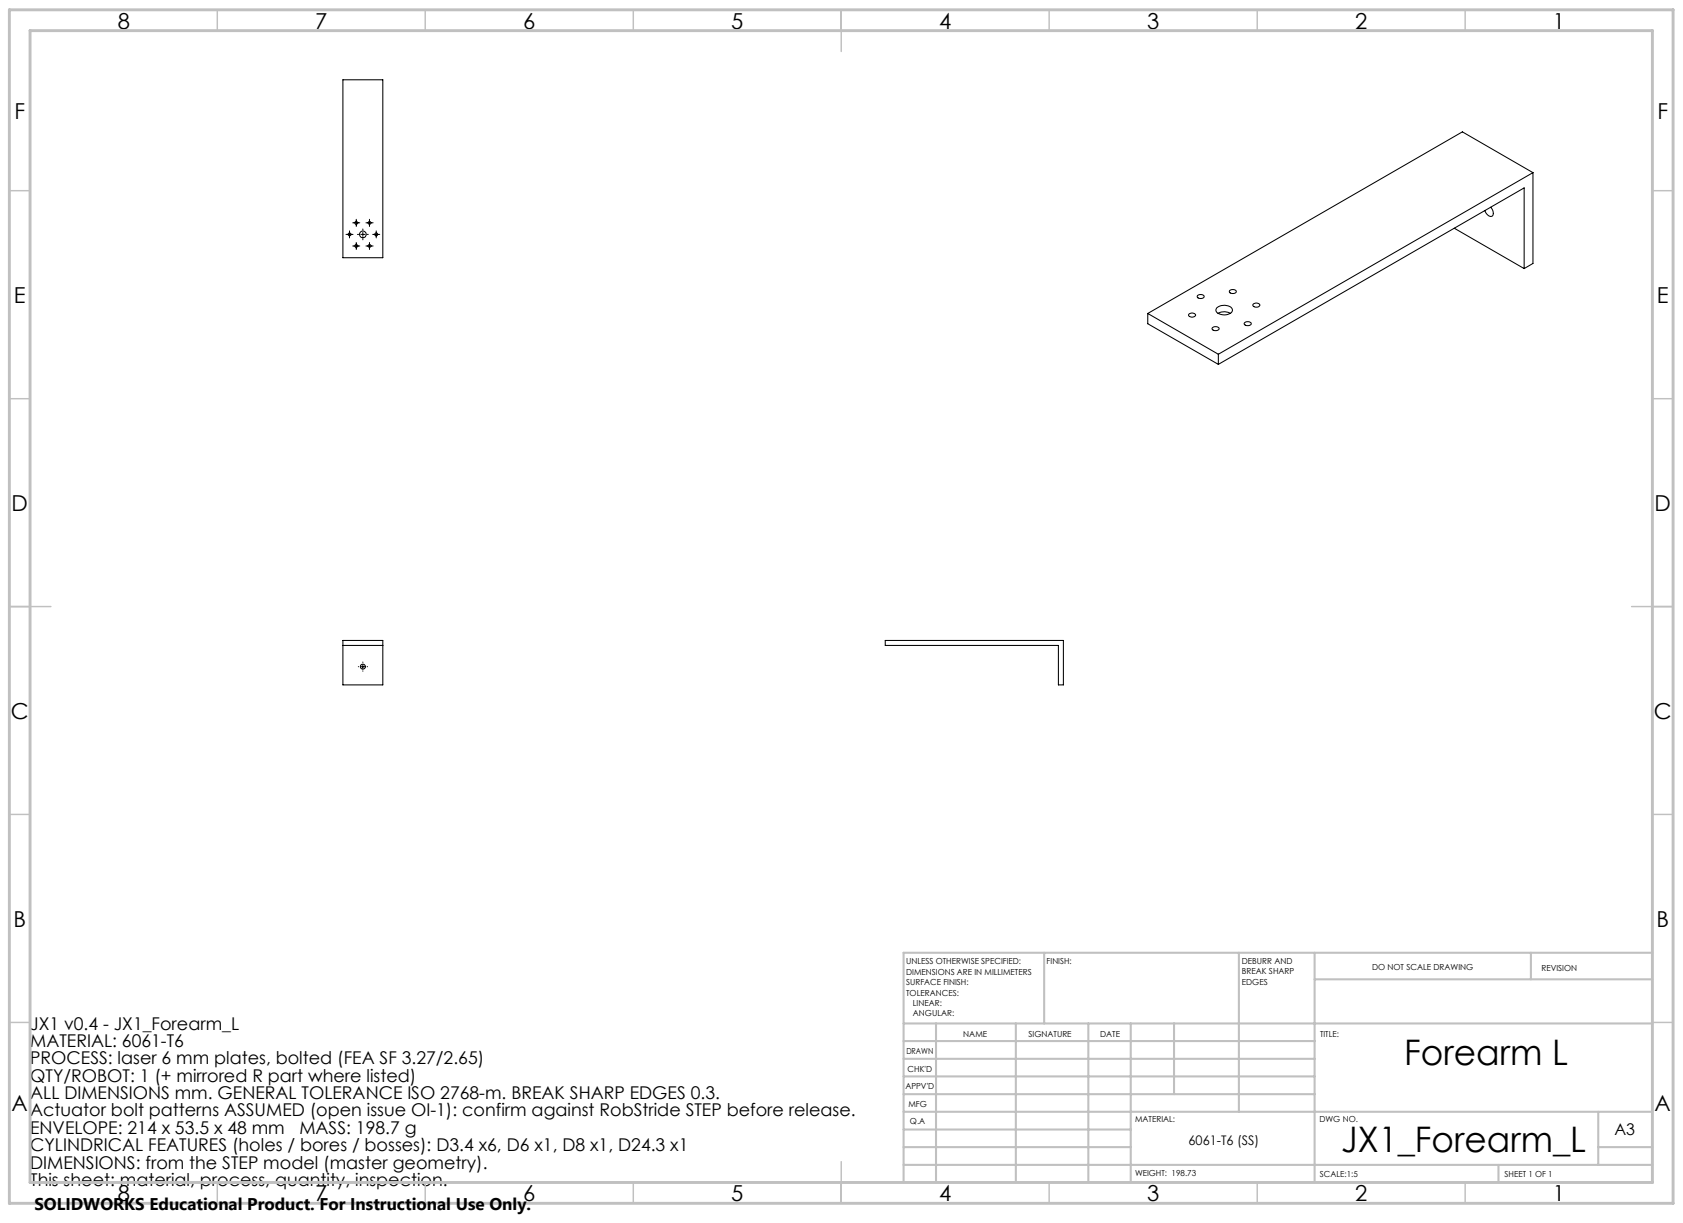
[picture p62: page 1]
FINISH:; DEBURR AND; BREAK SHARP; DO NOT SCALE DRAWING; REVISION; SCALE:1:5; SHEET 1 OF 1; WEIGHT: 198.73

UNLESS OTHERWISE SPECIFIED:
DIMENSIONS ARE IN MILLIMETERS
SURFACE FINISH:
TOLERANCES:
LINEAR:
ANGULAR:

JX1 v0.4 - JX1_Forearm_L
MATERIAL: 6061-T6
PROCESS: laser 6 mm plates, bolted (FEA SF 3.27/2.65)
QTY/ROBOT: 1 (+ mirrored R part where listed)
ALL DIMENSIONS mm. GENERAL TOLERANCE ISO 2768-m. BREAK SHARP EDGES 0.3.
Actuator bolt patterns ASSUMED (open issue OI-1): confirm against RobStride STEP before release.
ENVELOPE: 214 x 53.5 x 48 mm MASS: 198.7 g
CYLINDRICAL FEATURES (holes / bores / bosses): D3.4 x6, D6 x1, D8 x1, D24.3 x1
DIMENSIONS: from the STEP model (master geometry).
This sheet: material, process, quantity, inspection.
SOLIDWORKS Educational Product. For Instructional Use Only.

NAME | SIGNATURE | DATE | | | | TITLE: Forearm L

DRAWN
CHK'D
APPV'D
MFG
Q.A | | | | MATERIAL: | DWG NO. JX1_Forearm_L | A3 6061-T6 (SS)

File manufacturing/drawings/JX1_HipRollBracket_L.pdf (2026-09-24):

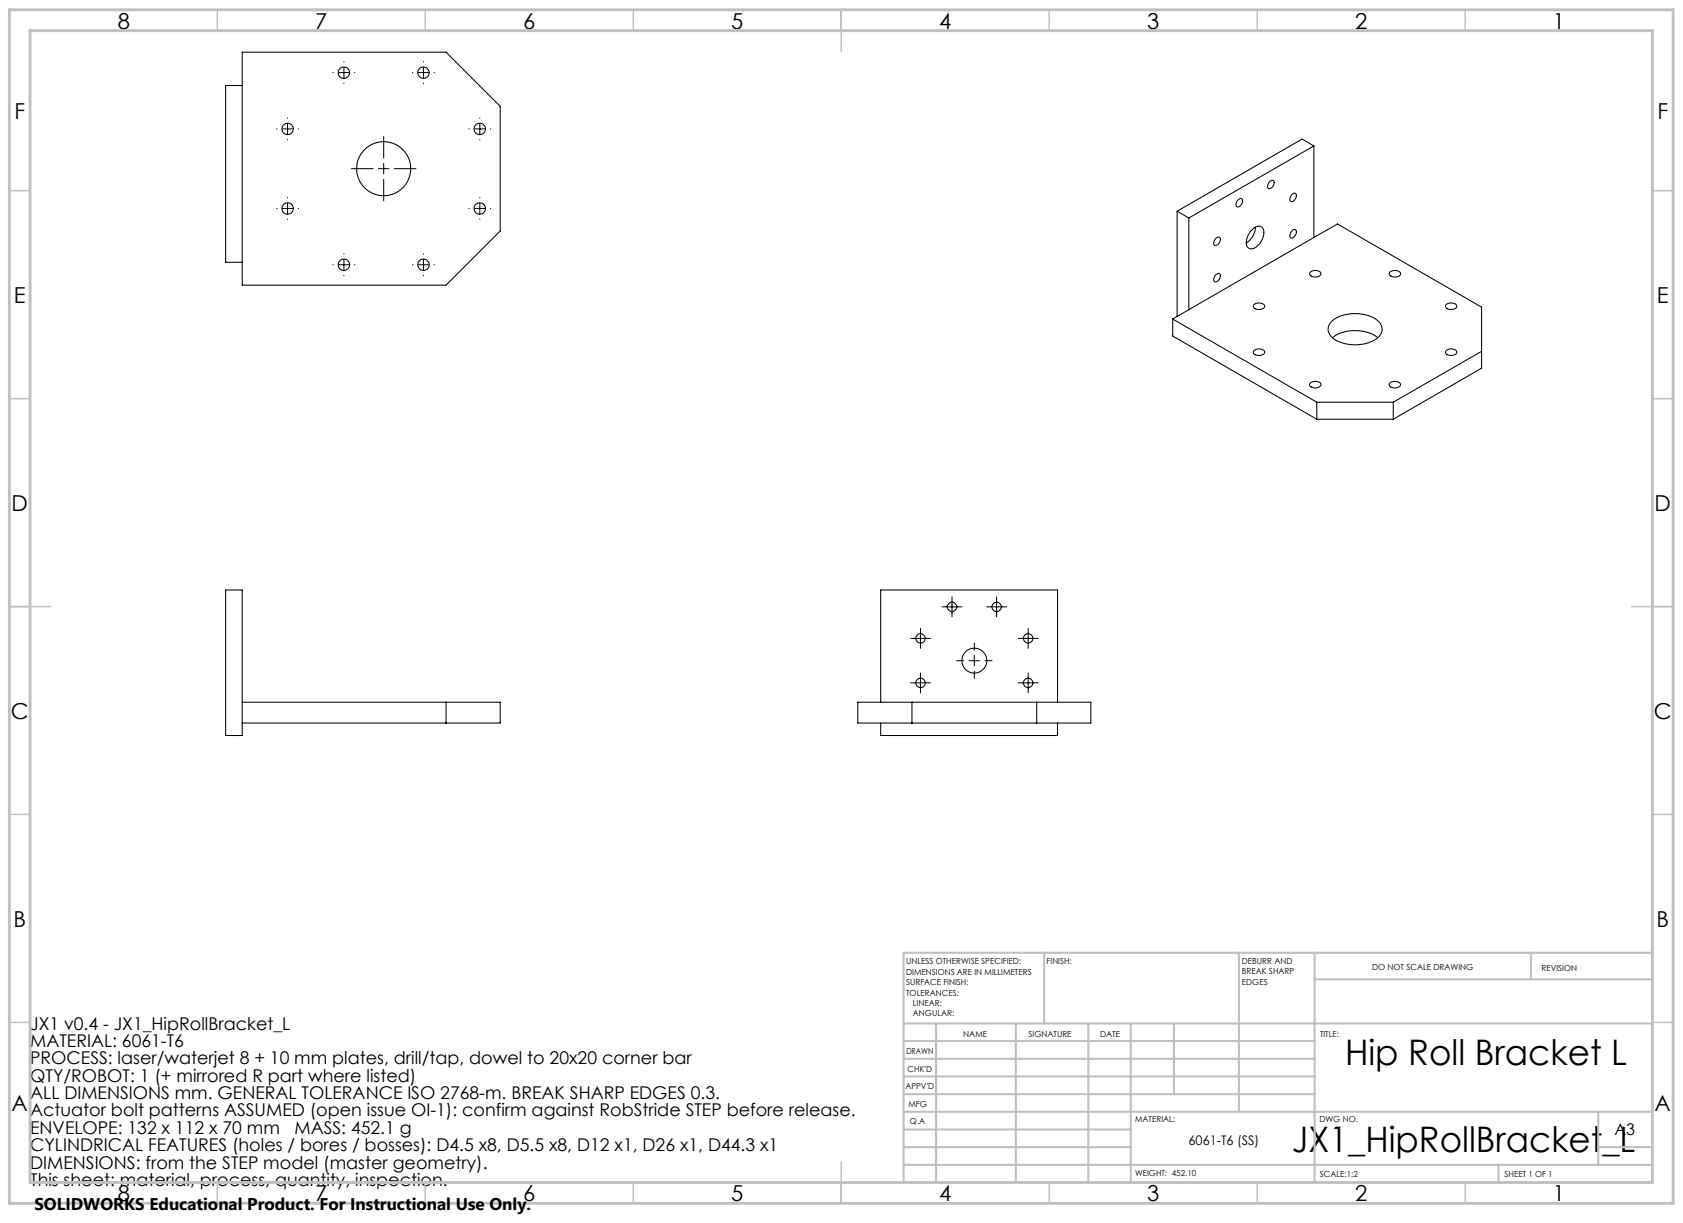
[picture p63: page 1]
FINISH:; DEBURR AND; BREAK SHARP; DO NOT SCALE DRAWING; REVISION; SCALE:1:2; SHEET 1 OF 1; WEIGHT: 452.10

UNLESS OTHERWISE SPECIFIED:
DIMENSIONS ARE IN MILLIMETERS
SURFACE FINISH:
TOLERANCES:
LINEAR:
ANGULAR:

JX1 v0.4 - JX1_HipRollBracket_L
MATERIAL: 6061-T6
PROCESS: laser/waterjet 8 + 10 mm plates, drill/tap, dowel to 20x20 corner bar
QTY/ROBOT: 1 (+ mirrored R part where listed)
ALL DIMENSIONS mm. GENERAL TOLERANCE ISO 2768-m. BREAK SHARP EDGES 0.3.
Actuator bolt patterns ASSUMED (open issue OI-1): confirm against RobStride STEP before release.
ENVELOPE: 132 x 112 x 70 mm MASS: 452.1 g
CYLINDRICAL FEATURES (holes / bores / bosses): D4.5 x8, D5.5 x8, D12 x1, D26 x1, D44.3 x1
DIMENSIONS: from the STEP model (master geometry).
This sheet: material, process, quantity, inspection.
SOLIDWORKS Educational Product. For Instructional Use Only.

NAME | SIGNATURE | DATE | | | | TITLE: Hip Roll Bracket L

DRAWN
CHK'D
APPV'D
MFG
Q.A | | | | MATERIAL: JX1_HipRollBracket_L | DWG NO. | A3 6061-T6 (SS)

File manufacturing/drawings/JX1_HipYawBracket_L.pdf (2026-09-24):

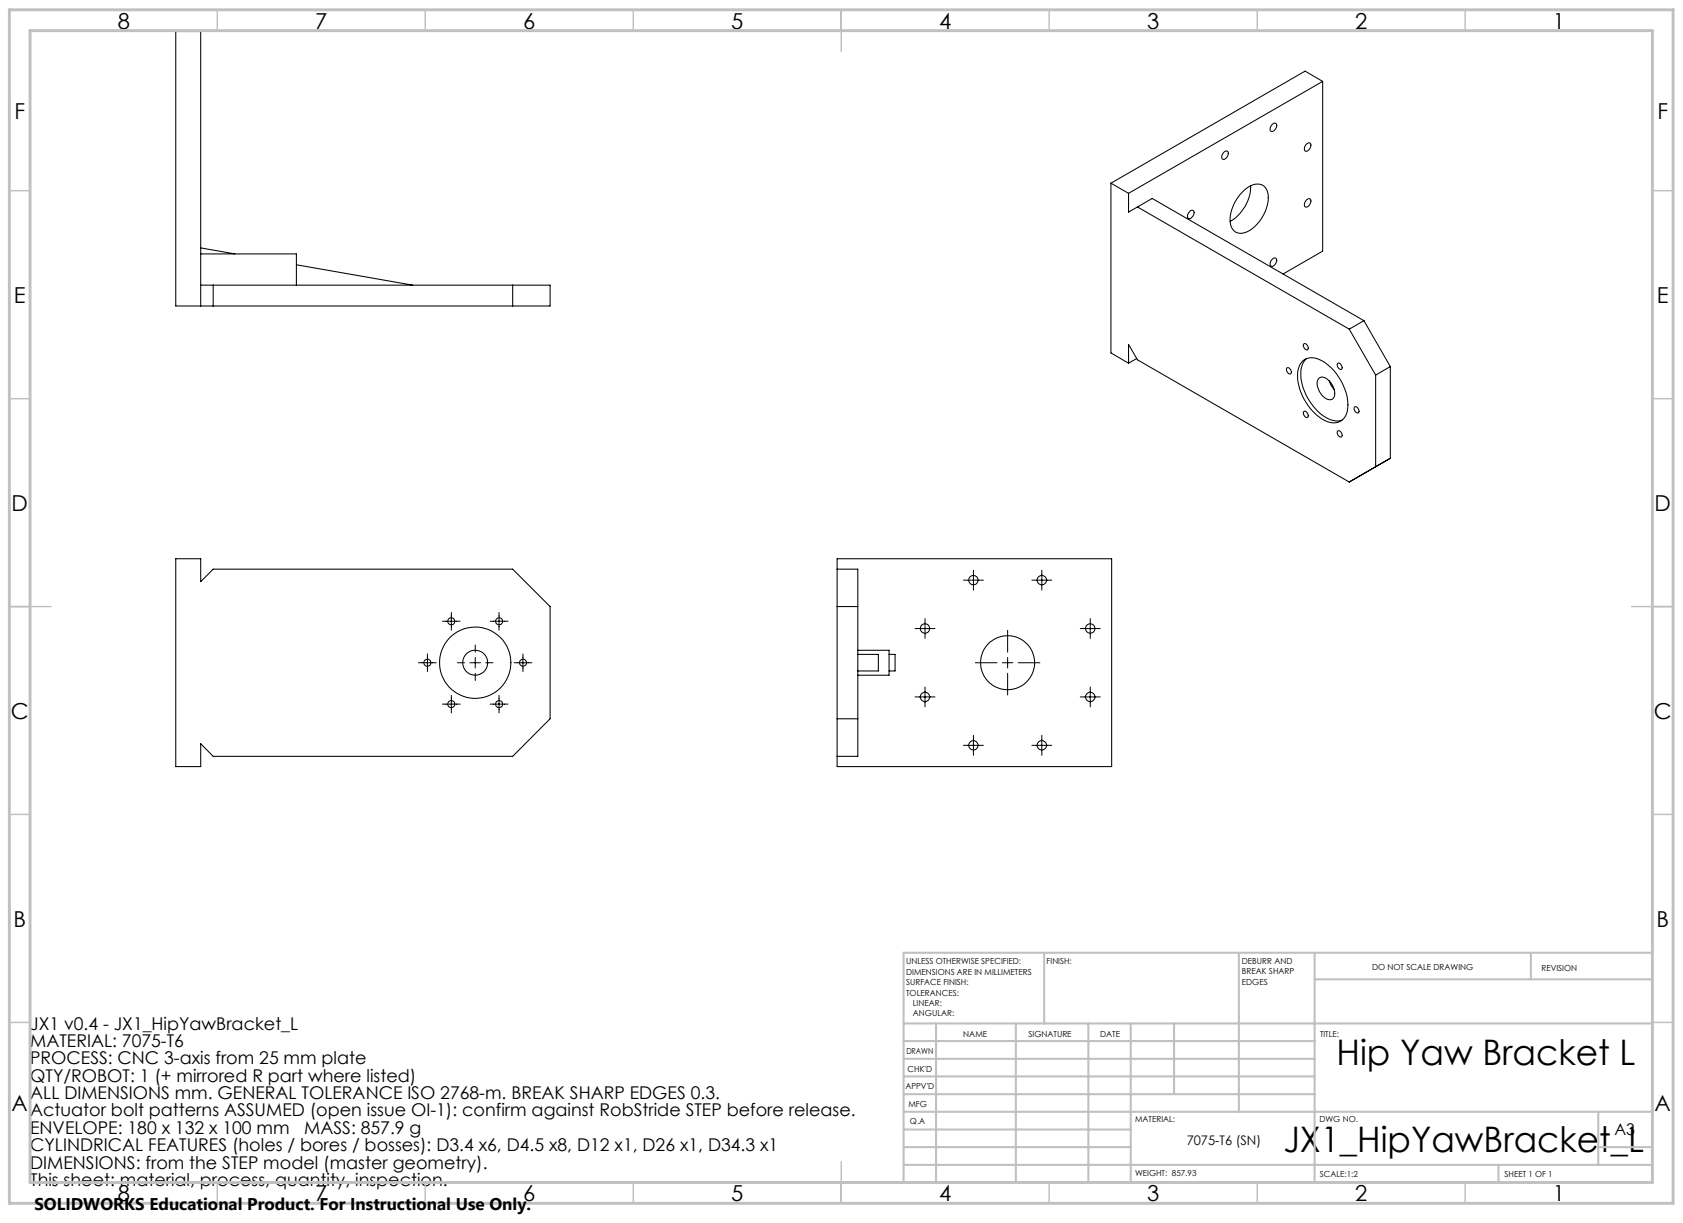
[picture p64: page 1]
FINISH:; DEBURR AND; BREAK SHARP; DO NOT SCALE DRAWING; REVISION; SCALE:1:2; SHEET 1 OF 1; WEIGHT: 857.93

UNLESS OTHERWISE SPECIFIED:
DIMENSIONS ARE IN MILLIMETERS
SURFACE FINISH:
TOLERANCES:
LINEAR:
ANGULAR:

JX1 v0.4 - JX1_HipYawBracket_L
MATERIAL: 7075-T6
PROCESS: CNC 3-axis from 25 mm plate
QTY/ROBOT: 1 (+ mirrored R part where listed)
ALL DIMENSIONS mm. GENERAL TOLERANCE ISO 2768-m. BREAK SHARP EDGES 0.3.
Actuator bolt patterns ASSUMED (open issue OI-1): confirm against RobStride STEP before release.
ENVELOPE: 180 x 132 x 100 mm MASS: 857.9 g
CYLINDRICAL FEATURES (holes / bores / bosses): D3.4 x6, D4.5 x8, D12 x1, D26 x1, D34.3 x1
DIMENSIONS: from the STEP model (master geometry).
This sheet: material, process, quantity, inspection.
SOLIDWORKS Educational Product. For Instructional Use Only.

NAME | SIGNATURE | DATE | | | | TITLE: Hip Yaw Bracket L

DRAWN
CHK'D
APPV'D
MFG
Q.A | | | | MATERIAL: JX1_HipYawBracket_L | DWG NO. | A3 7075-T6 (SN)

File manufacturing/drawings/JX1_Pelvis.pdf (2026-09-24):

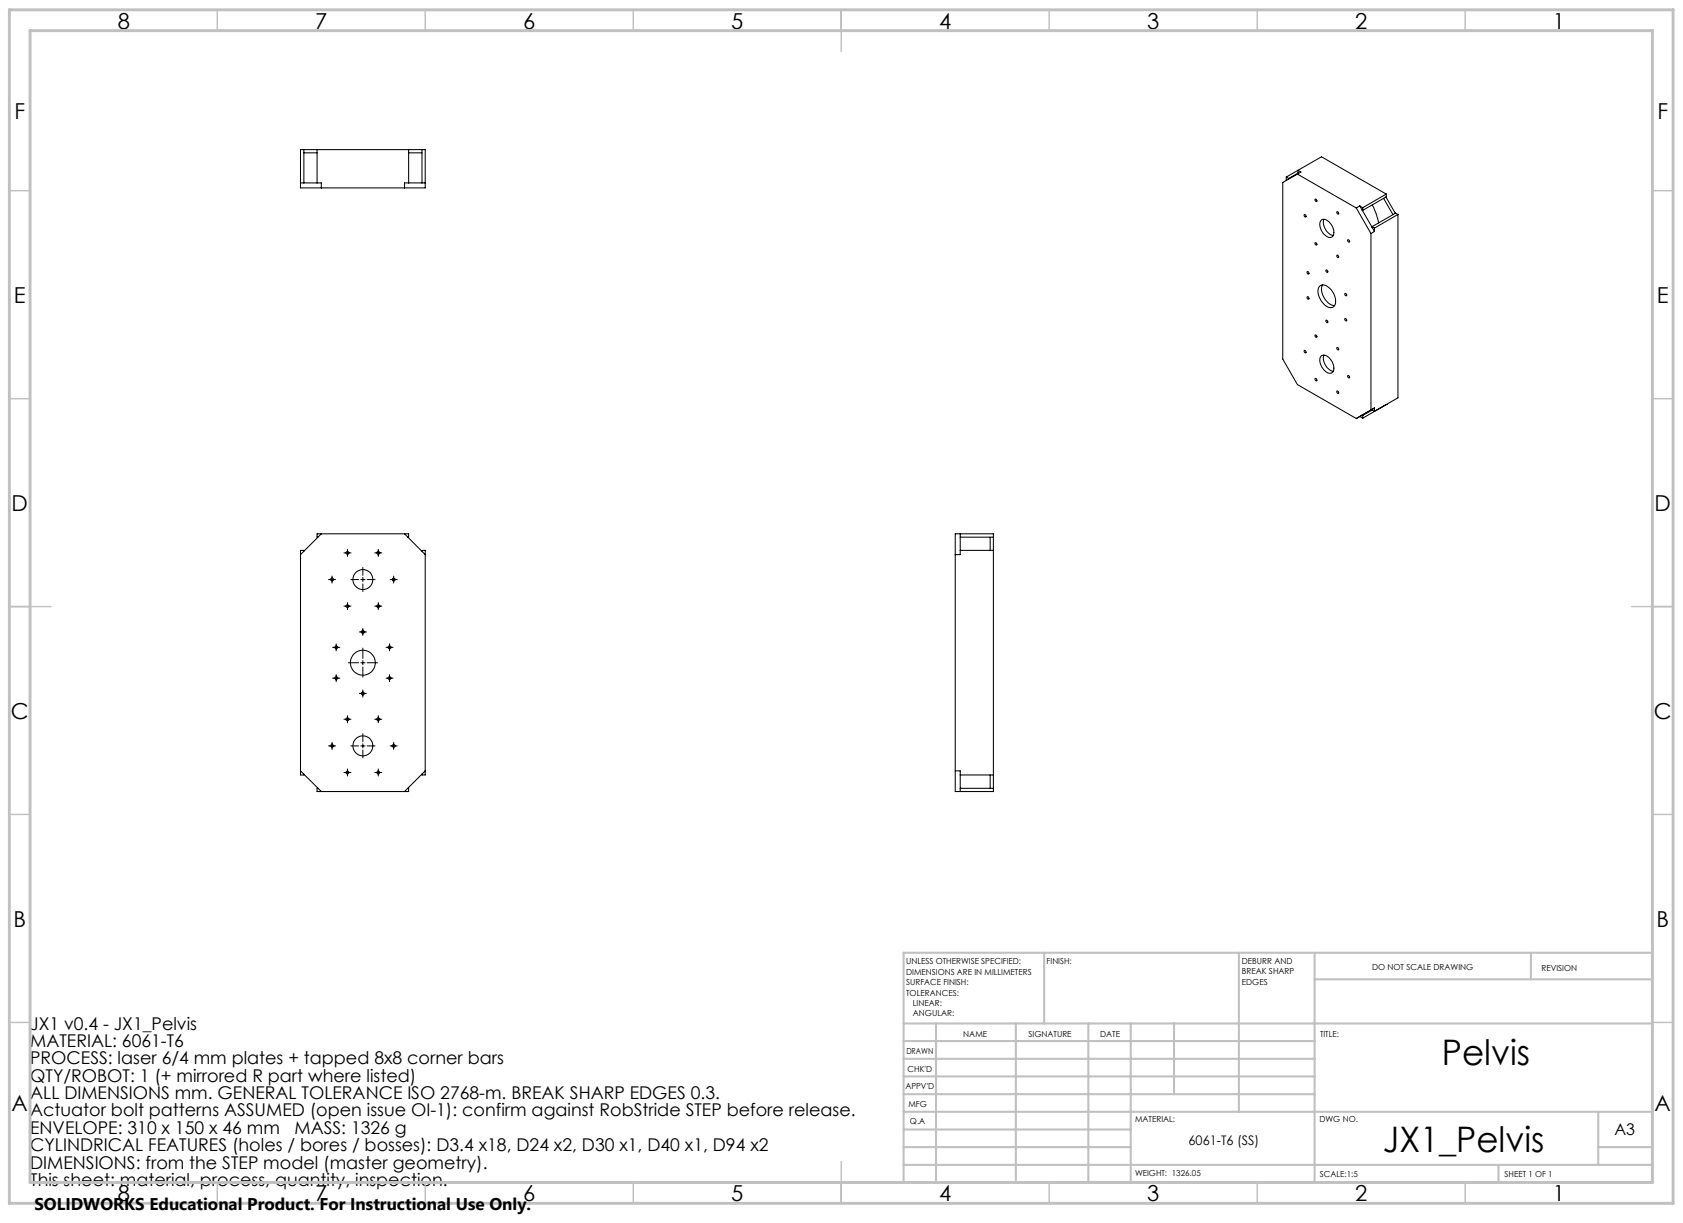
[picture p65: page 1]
FINISH:; DEBURR AND; BREAK SHARP; DO NOT SCALE DRAWING; REVISION; SCALE:1:5; SHEET 1 OF 1; WEIGHT: 1326.05

UNLESS OTHERWISE SPECIFIED:
DIMENSIONS ARE IN MILLIMETERS
SURFACE FINISH:
TOLERANCES:
LINEAR:
ANGULAR:

JX1 v0.4 - JX1_Pelvis
MATERIAL: 6061-T6
PROCESS: laser 6/4 mm plates + tapped 8x8 corner bars
QTY/ROBOT: 1 (+ mirrored R part where listed)
ALL DIMENSIONS mm. GENERAL TOLERANCE ISO 2768-m. BREAK SHARP EDGES 0.3.
Actuator bolt patterns ASSUMED (open issue OI-1): confirm against RobStride STEP before release.
ENVELOPE: 310 x 150 x 46 mm MASS: 1326 g
CYLINDRICAL FEATURES (holes / bores / bosses): D3.4 x18, D24 x2, D30 x1, D40 x1, D94 x2
DIMENSIONS: from the STEP model (master geometry).
This sheet: material, process, quantity, inspection.
SOLIDWORKS Educational Product. For Instructional Use Only.

NAME | SIGNATURE | DATE | | | | TITLE: Pelvis

DRAWN
CHK'D
APPV'D
MFG
Q.A | | | | MATERIAL: | DWG NO. JX1_Pelvis | A3 6061-T6 (SS)

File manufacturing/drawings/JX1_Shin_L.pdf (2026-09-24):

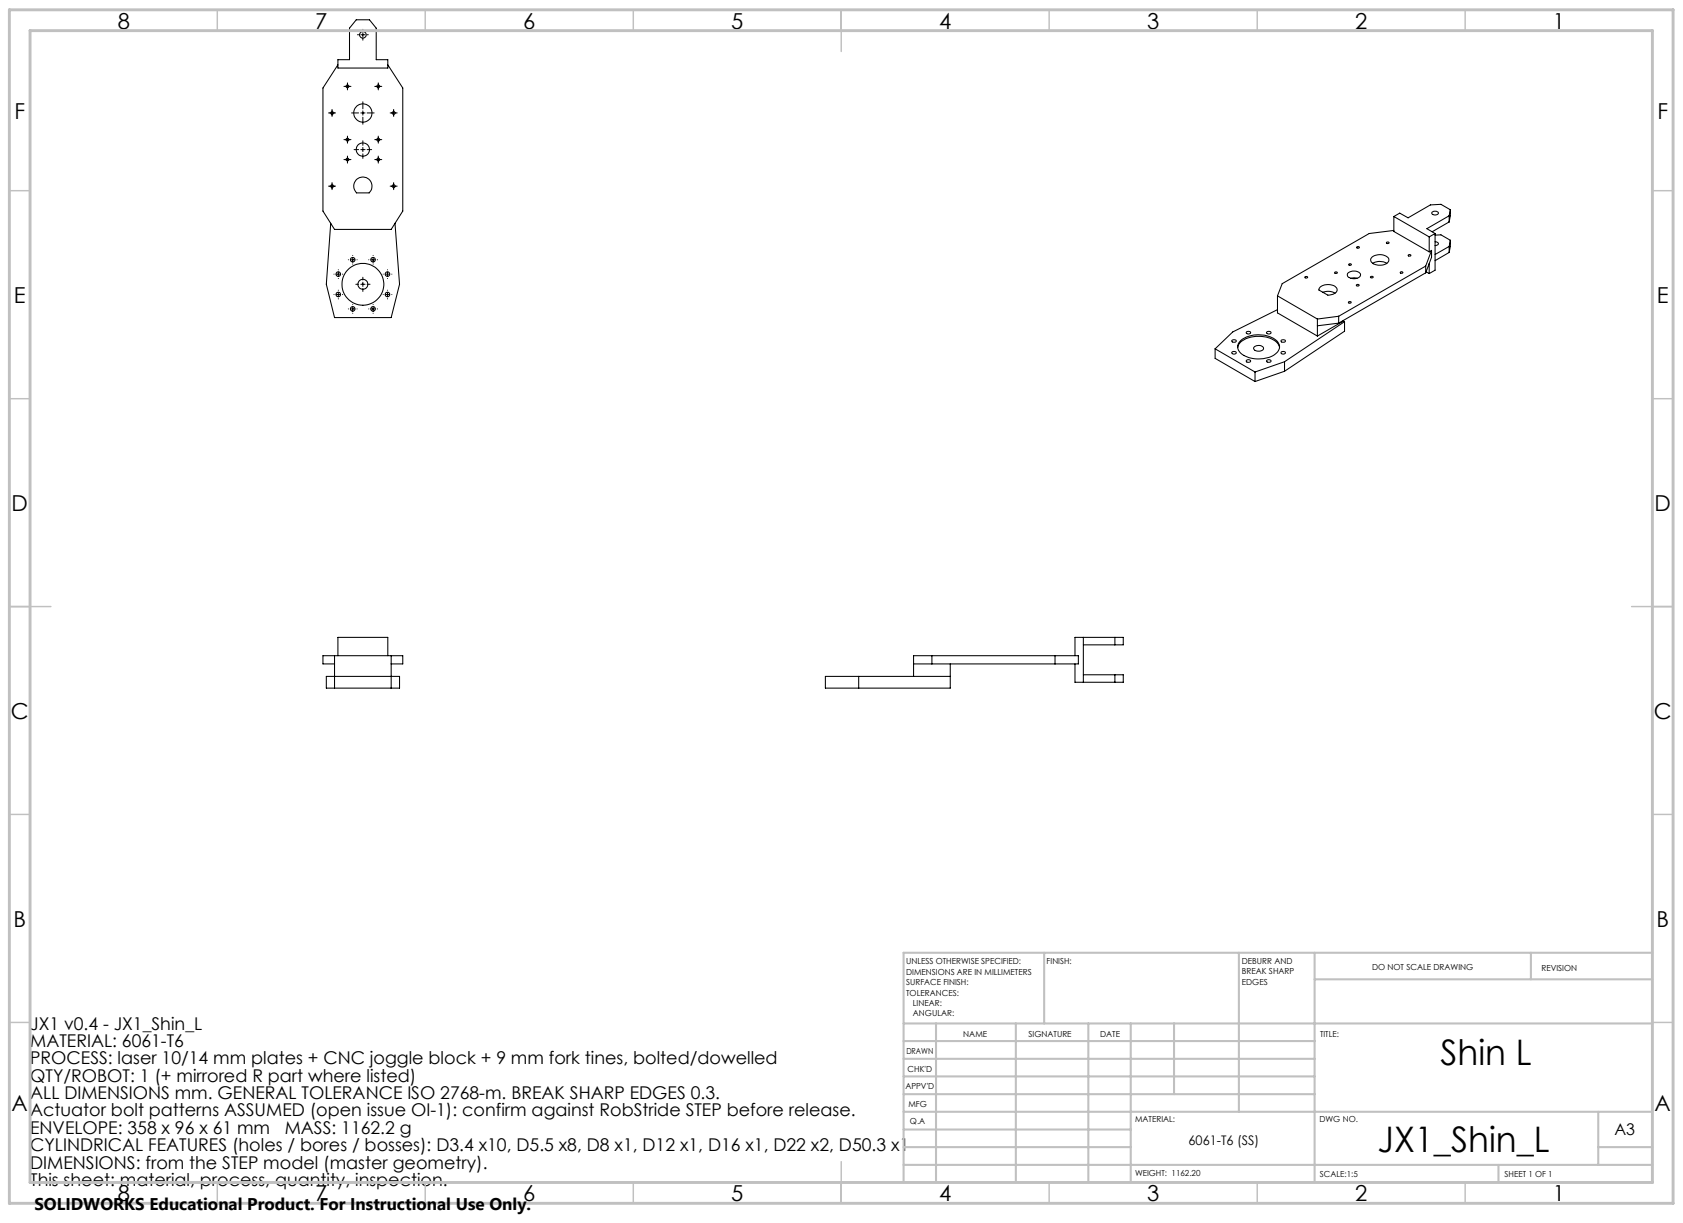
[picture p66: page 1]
FINISH:; DEBURR AND; BREAK SHARP; DO NOT SCALE DRAWING; REVISION; SCALE:1:5; SHEET 1 OF 1; WEIGHT: 1162.20

UNLESS OTHERWISE SPECIFIED:
DIMENSIONS ARE IN MILLIMETERS
SURFACE FINISH:
TOLERANCES:
LINEAR:
ANGULAR:

JX1 v0.4 - JX1_Shin_L
MATERIAL: 6061-T6
PROCESS: laser 10/14 mm plates + CNC joggle block + 9 mm fork tines, bolted/dowelled
QTY/ROBOT: 1 (+ mirrored R part where listed)
ALL DIMENSIONS mm. GENERAL TOLERANCE ISO 2768-m. BREAK SHARP EDGES 0.3.
Actuator bolt patterns ASSUMED (open issue OI-1): confirm against RobStride STEP before release.
ENVELOPE: 358 x 96 x 61 mm MASS: 1162.2 g
CYLINDRICAL FEATURES (holes / bores / bosses): D3.4 x10, D5.5 x8, D8 x1, D12 x1, D16 x1, D22 x2, D50.3 x1
DIMENSIONS: from the STEP model (master geometry).
This sheet: material, process, quantity, inspection.
SOLIDWORKS Educational Product. For Instructional Use Only.

NAME | SIGNATURE | DATE | | | | TITLE: Shin L

DRAWN
CHK'D
APPV'D
MFG
Q.A | | | | MATERIAL: | DWG NO. JX1_Shin_L | A3 6061-T6 (SS)

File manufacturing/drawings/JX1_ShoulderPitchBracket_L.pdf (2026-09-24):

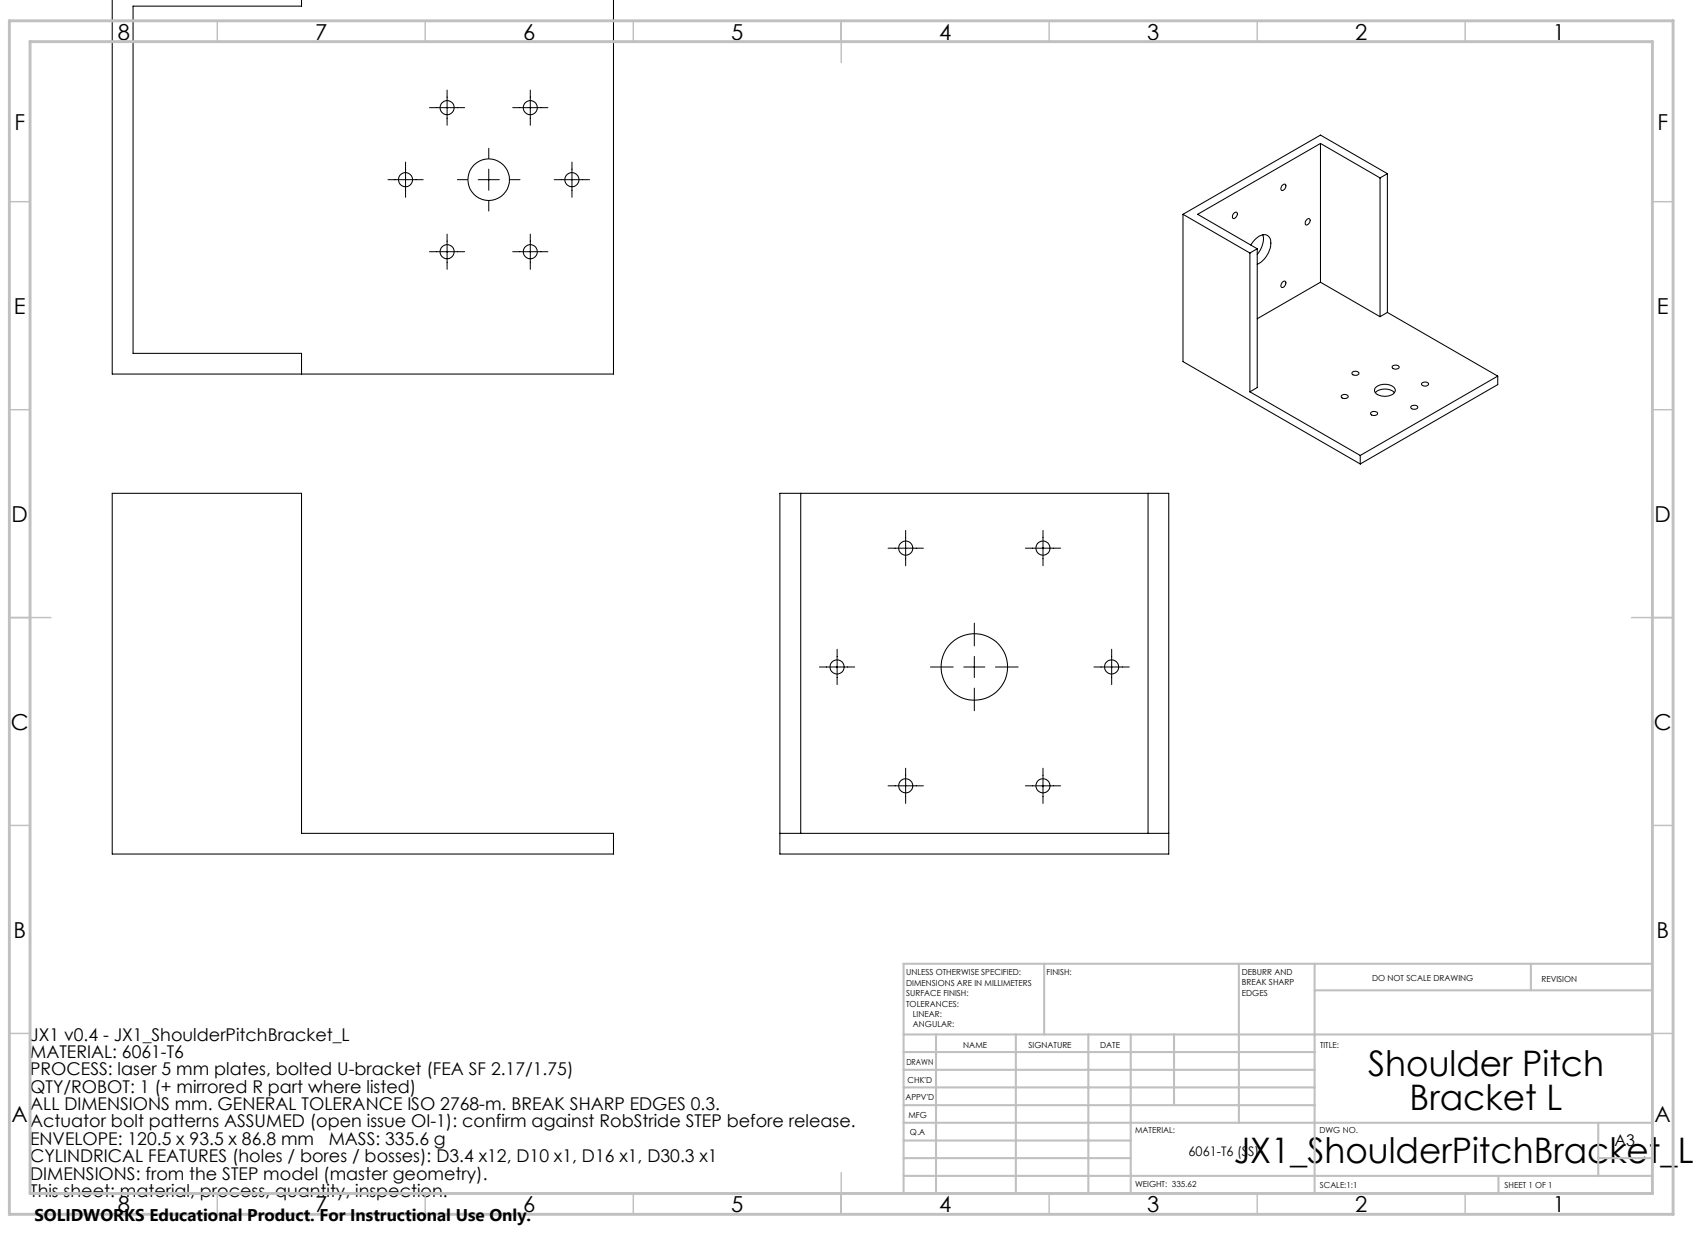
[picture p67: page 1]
FINISH:; DEBURR AND; BREAK SHARP; DO NOT SCALE DRAWING; REVISION; SCALE:1:1; SHEET 1 OF 1; WEIGHT: 335.62

UNLESS OTHERWISE SPECIFIED:
DIMENSIONS ARE IN MILLIMETERS
SURFACE FINISH:
TOLERANCES:
LINEAR:
ANGULAR:

JX1 v0.4 - JX1_ShoulderPitchBracket_L
MATERIAL: 6061-T6
PROCESS: laser 5 mm plates, bolted U-bracket (FEA SF 2.17/1.75)
QTY/ROBOT: 1 (+ mirrored R part where listed)
ALL DIMENSIONS mm. GENERAL TOLERANCE ISO 2768-m. BREAK SHARP EDGES 0.3.
Actuator bolt patterns ASSUMED (open issue OI-1): confirm against RobStride STEP before release.
ENVELOPE: 120.5 x 93.5 x 86.8 mm MASS: 335.6 g
CYLINDRICAL FEATURES (holes / bores / bosses): D3.4 x12, D10 x1, D16 x1, D30.3 x1
DIMENSIONS: from the STEP model (master geometry).
This sheet: material, process, quantity, inspection.
SOLIDWORKS Educational Product. For Instructional Use Only.

NAME | SIGNATURE | DATE | | | | TITLE: Shoulder Pitch Bracket L

DRAWN
CHK'D
APPV'D
MFG
Q.A | | | | MATERIAL: | DWG NO. | A3 6061-T6 (SS)

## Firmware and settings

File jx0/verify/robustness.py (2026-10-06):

"""Does JX0 really walk? Robustness of the verified gaits + the robot's balance controller (jx0bot/balance.py) when the
real robot differs from the model, and when it is pushed.

Model-error trials: each trial walks a gait in MuJoCo with randomly wrong "reality":
  servo stiffness x0.6-1.4 and damping x0.5-1.5, servo torque/speed x0.85-1.0 (battery sag), bus latency 0-40 ms,
  gear backlash 0-0.6 deg, IMU noise (0.3 deg, 0.02 rad/s) and bias +-1 deg, upper-body mass x0.9-1.1 with its centre
  of mass off by up to 8 mm (x) / 4 mm (y), floor friction 0.5-1.0, floor slope up to +-2 deg in both directions.
Push trials: a sideways shove on the torso (0.12 s) at 24 moments of a 10-step walk, both directions.

    python jx0/verify/robustness.py baseline        # evaluate the current balance gains
    python jx0/verify/robustness.py tune            # random search for better gains, then evaluate them
    -> jx0/results/verify_robustness.json
"""
from __future__ import annotations

import json
import math
import os
import sys
import time
from collections import deque
from multiprocessing import Pool
from pathlib import Path

import numpy as np

ROOT = Path(__file__).resolve().parents[2]
sys.path.insert(0, str(ROOT / "jx0" / "sim"))           # module level: Windows worker processes re-import this file
sys.path.insert(0, str(ROOT / "jx0" / "software"))
os.environ["JX0_STL_DIR"] = str(ROOT / "nonexistent")   # physics only: plain box visuals load faster
OUT = ROOT / "jx0" / "results" / "verify_robustness.json"
MC_GAITS = ["forward", "forward_4", "backward_4", "turn_left_2", "turn_right_2", "side_left_2", "side_right_2"]
_CACHE = {}


def _setup(gait, overrides=None):
    key = (gait, json.dumps(overrides or {}, sort_keys=True))
    if key not in _CACHE:
        os.environ["JX0_STL_DIR"] = str(ROOT / "nonexistent")       # physics only: plain box visuals load faster
        sys.path.insert(0, str(ROOT / "jx0" / "sim"))
        sys.path.insert(0, str(ROOT / "jx0" / "software"))
        import mujoco
        import walk_jx0 as W
        from jx1calc.design import Design
        design = Design(W.DESIGN)
        xml = W.build(design)
        m = mujoco.MjModel.from_xml_string(xml)
        saved, saved_g = dict(W.COMMON), dict(W.GAITS[gait])
        ov = dict(overrides or {})
        if "step_time" in ov:                                        # per-gait parameter
            W.GAITS[gait]["step_time"] = ov.pop("step_time")
        W.COMMON.update(ov)
        try:
            g, res = W.plan(m, design, gait)
        finally:
            W.COMMON.clear()
            W.COMMON.update(saved)
            W.GAITS[gait] = saved_g
        _CACHE[key] = (xml, g, res, design.act_classes["ST"])
    return _CACHE[key]


def nominal():
    return {"kp": 1.0, "kd": 1.0, "stall": 1.0, "latency": 0, "backlash_deg": 0.0, "imu_deg": 0.0, "gyro": 0.0,
            "bias_deg": [0.0, 0.0], "mass": 1.0, "com_mm": [0.0, 0.0], "mu": 0.9, "slope_deg": [0.0, 0.0]}


def sample(rng, latencies=(0, 1, 2)):
    return {"kp": rng.uniform(0.6, 1.4), "kd": rng.uniform(0.5, 1.5), "stall": rng.uniform(0.85, 1.0),
            "latency": int(rng.choice(latencies)), "backlash_deg": rng.uniform(0.0, 0.6), "imu_deg": 0.3, "gyro": 0.02,
            "bias_deg": list(rng.uniform(-1.0, 1.0, 2)), "mass": rng.uniform(0.9, 1.1),
            "com_mm": [rng.uniform(-8, 8), rng.uniform(-4, 4)], "mu": rng.uniform(0.5, 1.0),
            "slope_deg": list(rng.uniform(-2.0, 2.0, 2))}


GAIT_DIR = ROOT / "jx0" / "software" / "jx0bot" / "gaits"
ENC = 2 * math.pi / 4096                                   # STS3215 encoder step: what the robot reads back


def trial(spec):
    """One walk. spec: gait, scenario, gains (balance.py overrides), push (t, N toward +y, s) or None, seed;
    capture: True plays the gait through jx0bot.stepper (capture-point stepping, as the robot does), with `params`."""
    import mujoco
    import walk_jx0 as W
    from jx0bot.balance import Balance
    from jx0bot.stepper import CaptureStepper
    xml, g, res, st = _setup(spec["gait"], spec.get("gait_overrides"))
    sc, rng = spec["scenario"], np.random.default_rng(spec.get("seed", 0))
    m = mujoco.MjModel.from_xml_string(xml)
    oid = lambda kind, n: mujoco.mj_name2id(m, kind, n)  # noqa: E731
    torso = oid(mujoco.mjtObj.mjOBJ_BODY, "torso")
    m.body_mass[torso] *= sc["mass"]
    m.body_ipos[torso][:2] += np.array(sc["com_mm"]) * 1e-3
    for gname in ("l_foot_geom", "r_foot_geom", "floor"):
        m.geom_friction[oid(mujoco.mjtObj.mjOBJ_GEOM, gname)][0] = sc["mu"]
    ax, ay = (math.radians(v) for v in sc["slope_deg"])
    m.opt.gravity[:] = 9.81 * np.array([math.sin(ay) * math.cos(ax), -math.sin(ax), -math.cos(ax) * math.cos(ay)])
    d = mujoco.MjData(m)

    t_ref, q_ref, contact = res["t"], res["qpos"], res["plan"].contact
    names = [f"{s}_{j}" for s in "lr" for j in W.LEG_JOINTS] + [f"{s}_{j}" for s in "lr" for j in W.ARM_JOINTS] + ["neck_yaw"]
    adr = {n: (m.jnt_qposadr[oid(mujoco.mjtObj.mjOBJ_JOINT, n)], m.jnt_dofadr[oid(mujoco.mjtObj.mjOBJ_JOINT, n)]) for n in names}
    act = {n: oid(mujoco.mjtObj.mjOBJ_ACTUATOR, n) for n in names}
    servo = W.ServoModel(st["stall_torque_nm"] * sc["stall"], st["no_load_speed_rad_s"] * sc["stall"], 60.0 * sc["kp"], 0.6 * sc["kd"])
    d.qpos[:] = q_ref[0]
    for n, v in W.arm_goals(q_ref[0], q_ref[0], adr).items():
        d.qpos[adr[n][0]] = v
    d.qpos[2] += 0.002
    mujoco.mj_forward(m, d)
    dt, T = m.opt.timestep, float(t_ref[-1])
    frame = 1.0 / spec.get("bus_hz", W.BUS_HZ)
    period = int(round(frame / dt))
    goal = {n: float(d.qpos[adr[n][0]]) for n in names}
    lag = int(round(sc["latency"] * 0.02 / frame))                 # latency is given in 20 ms units
    pipe = deque([dict(goal)] * (lag + 1), maxlen=lag + 1)
    bal = Balance(spec.get("gains"), dt=frame)
    stepper = None
    if spec.get("capture"):
        stepper = CaptureStepper(json.loads((GAIT_DIR / f"{spec['gait']}.json").read_text(encoding="utf-8")),
                                 spec.get("gains"), spec.get("params"))
        stepper.start()
    bl = math.radians(sc["backlash_deg"]) / 2
    bias = [math.radians(v) for v in sc["bias_deg"]]
    fell, max_tilt, hist = False, 0.0, []
    loads = {} if spec.get("loads") else None
    series = {} if spec.get("series") else None
    for k in range(int(T / dt)):
        t = k * dt
        i = min(int(round(t / g.dt)), len(t_ref) - 1)
        roll, pitch, yaw = W.rpy(d.qpos[3:7])
        if k % period == 0:
            n_deg = math.radians(sc["imu_deg"])
            r_m, p_m = roll + bias[0] + rng.normal(0, n_deg), pitch + bias[1] + rng.normal(0, n_deg)
            wx, wy = d.qvel[3] + rng.normal(0, sc["gyro"]), d.qvel[4] + rng.normal(0, sc["gyro"])
            if stepper is not None:
                q_enc = {n: round(float(d.qpos[adr[n][0]]) / ENC) * ENC for n in names}
                new = {**goal, **stepper.frame(min(int(round(t / frame)), stepper.n - 1), q_enc, r_m, p_m, wx, wy)}
            else:
                corr = bal.update(r_m, p_m, wx, wy, contact[min(i, len(contact) - 1)])
                arms = W.arm_goals(q_ref[i], q_ref[0], adr)
                new = {n: float((q_ref[i, adr[n][0]] if n.split("_", 1)[1] in W.LEG_JOINTS else arms.get(n, 0.0)) + corr.get(n, 0.0))
                       for n in names}
            pipe.append(new)
            goal = pipe[0]                                  # what the servos act on, `latency` frames late
        for n in names:
            qa, da = adr[n]
            err = goal[n] - d.qpos[qa]
            err = 0.0 if abs(err) < bl else err - math.copysign(bl, err)       # gear backlash
            d.ctrl[act[n]] = servo.torque(d.qpos[qa] + err, d.qpos[qa], d.qvel[da])
        if spec.get("push") is not None:
            tp, f, dur = spec["push"][:3]
            d.xfrc_applied[torso, spec["push"][3] if len(spec["push"]) > 3 else 1] = f if tp <= t < tp + dur else 0.0
        mujoco.mj_step(m, d)
        if loads is not None and k % 2 == 0:
            joint_loads(m, d, loads)
        if series is not None and k % 10 == 0:
            joint_wrench_series(m, d, series)
        if k % 10 == 0:
            tilt = math.degrees(math.hypot(roll, pitch))
            max_tilt = max(max_tilt, tilt)
            hist.append((*d.qpos[:2], *q_ref[i, :2], yaw, W.rpy(q_ref[i, 3:7])[2], roll, pitch, t))
            if d.qpos[2] < 0.13 or tilt > 30:
                fell = True
                break
    h = np.array(hist)
    dist_plan = float(np.linalg.norm(q_ref[-1, :2] - q_ref[0, :2]))
    pos_err = float(np.linalg.norm(h[-1, 0:2] - h[-1, 2:4]))
    head_err = math.degrees((h[-1, 4] - h[-1, 5] + math.pi) % (2 * math.pi) - math.pi)
    ok = (not fell) and pos_err <= 0.05 + 0.10 * dist_plan and abs(head_err) < 10.0
    return {"gait": spec["gait"], "fell": fell, "pass": bool(ok), "pos_err_m": round(pos_err, 3),
            "heading_err_deg": round(head_err, 1), "max_tilt_deg": round(max_tilt, 1), "push": spec.get("push"),
            "end_roll_deg": round(math.degrees(h[-1, 6]), 1), "end_pitch_deg": round(math.degrees(h[-1, 7]), 1),
            "end_t_s": round(float(h[-1, 8]), 2), **({"loads": loads} if loads is not None else {}),
            **({"series": series} if series is not None else {})}


LOAD_JOINTS = [f"{s}_{j}" for s in "lr" for j in ("hip_yaw", "hip_roll", "hip_pitch", "knee", "ankle_pitch", "ankle_roll")]


def _servo_points():
    """Per leg joint: offsets along the joint axis (m, left leg; the right mirrors the y-axis joints) from the joint's
    anchor to the servo's output horn face and to the servo's centre (the middle of a U-bracket's two arms)."""
    sys.path.insert(0, str(ROOT / "jx0" / "cad"))
    import geometry as G
    hf = G.HF / 1000
    return {"hip_yaw": (G.ZY / 1000, (G.ZY + G.HF) / 1000), "hip_roll": (G.XR / 1000, (G.XR - G.HF) / 1000),
            "hip_pitch": (hf, 0.0), "knee": (hf, 0.0), "ankle_pitch": (hf, 0.0),
            "ankle_roll": (G.XA / 1000, (G.XA - G.HF) / 1000)}


_SP = None


def joint_wrench_series(m, d, series):
    """Left-leg joints: the 6-axis load (force N, moment N m about the servo's centre) the joint passes between its two
    links, expressed in the parent link's frame and in the child link's frame (verify_fea superposes per instant)."""
    import mujoco
    global _SP
    _SP = _SP or _servo_points()
    mujoco.mj_rnePostConstraint(m, d)
    c = d.subtree_com[0]
    for n in LOAD_JOINTS[:6]:
        j = mujoco.mj_name2id(m, mujoco.mjtObj.mjOBJ_JOINT, n)
        b = m.jnt_bodyid[j]
        a, p = d.xaxis[j], d.xanchor[j]
        tau_c, f = d.cfrc_int[b][:3], d.cfrc_int[b][3:]
        q = p + a * _SP[n[2:]][1]
        tq = tau_c + np.cross(c - q, f)
        Rp, Rc = d.xmat[m.body_parentid[b]].reshape(3, 3), d.xmat[b].reshape(3, 3)
        e = series.setdefault(n, {"parent": [], "child": []})
        e["parent"].append([round(float(v), 4) for v in np.concatenate([Rp.T @ f, Rp.T @ tq])])
        e["child"].append([round(float(v), 4) for v in np.concatenate([Rc.T @ f, Rc.T @ tq])])


YAW_RING_R = 0.016           # m: effective radius of the hip-yaw thrust ring's contact (11.5..19 mm ring)
KEEP_R, KEEP_CAP = 0.0175, 100.0   # m: radius of the ring's and the keeper lip's contact on the disc rim; N: the most the
                                   # keeper's lip is designed for (verify_fea); beyond it the yaw servo's shaft takes the rest


def keeper_arc(side):
    """The keeper's arc (degrees, pelvis frame) for the left ('l') or right ('r') leg."""
    sys.path.insert(0, str(ROOT / "jx0" / "cad"))
    import geometry as G
    a0, a1 = G.KEEP_ARC
    return (a0, a1) if side == "l" else (-a1, -a0)


def keeper_split(M, C, arc, cap=KEEP_CAP, R=KEEP_R, n=49):
    """How the hip-yaw disc's load is shared, instant by instant (vectorised over T instants).
    M (T, 2): bending moment the pelvis passes to the leg at the disc (N m, pelvis frame); C (T,): the disc's
    compression into the thrust ring (N, minus the axial force). The thrust ring (a full circle) can only push the disc
    down, the keeper's lip (only on its arc) only up. Least-force contact pair that carries C and M; if none exists
    within `cap`, the yaw servo's shaft takes the smallest leftover bending.
    Returns lip force L, ring force N (T,), shaft bending (T,) N m, lip angle, ring angle (T,) degrees."""
    M = np.atleast_2d(np.asarray(M, float))
    C = np.atleast_1d(np.asarray(C, float))
    th = np.radians(np.linspace(arc[0], arc[1], n))
    v = np.stack([np.sin(th), -np.cos(th)], 1)                # moment direction of a lip push at each arc point
    a = M / R
    m = np.linalg.norm(a, axis=1)
    den = a @ v.T + C[:, None]
    with np.errstate(divide="ignore", invalid="ignore"):
        L = (m[:, None] ** 2 - C[:, None] ** 2) / (2 * den)
    N = C[:, None] + L
    good = (den > 1e-9) & (L >= 0) & (N >= 0) & (L <= cap)
    score = np.where(good, np.maximum(L, N), np.inf)
    k = score.argmin(1)
    feasible = np.isfinite(score.min(1))
    ring_only = (C > 0) & (m <= C)
    # no contact pair within the cap (mostly the swing leg hanging from the disc): the least lip force that leaves the
    # shaft within 0.01 N m of the smallest bending it can be left with
    idx = np.arange(len(C))
    Lc, kc, shaft_c = np.zeros(len(C)), np.zeros(len(C), int), np.zeros(len(C))
    bad = np.nonzero(~feasible & ~ring_only)[0]
    if len(bad):
        Ls = np.array([0.0, 2.0, 5.0, 10.0, 20.0, 35.0, 50.0, 70.0, cap])
        ab = a[bad][:, None, None, :]
        lv = Ls[None, :, None, None] * v[None, None, :, :]
        lift = np.maximum(0.0, Ls[None, :, None] + C[bad][:, None, None])            # the ring cannot pull
        ex = np.maximum(0.0, np.linalg.norm(ab - lv, axis=3) - lift) * R               # (nb, nL, ntheta)
        best_th = ex.argmin(2)
        ex_l = np.take_along_axis(ex, best_th[:, :, None], 2)[:, :, 0]                # (nb, nL)
        pick = (ex_l <= ex_l.min(1, keepdims=True) + 0.01).argmax(1)
        Lc[bad], kc[bad] = Ls[pick], best_th[np.arange(len(bad)), pick]
        shaft_c[bad] = ex_l[np.arange(len(bad)), pick]
    k = np.where(feasible, k, kc)
    Lk = np.where(ring_only, 0.0, np.where(feasible, L[idx, k], Lc))
    Nk = np.where(ring_only, np.maximum(C, 0.0), np.maximum(C + Lk, 0.0))
    shaft = np.where(ring_only | feasible, 0.0, shaft_c)
    th_l = np.degrees(th[k])
    u = a - Lk[:, None] * v[k]                                  # ring force direction: N u_N = M/R - L v_L
    th_n = np.degrees(np.arctan2(-u[:, 0], u[:, 1]))
    return Lk, Nk, shaft, th_l, th_n


def joint_loads(m, d, peaks):
    """Peak loads each leg joint transmits (the parent link on the child): torque about the axis (what the servo drives),
    bending moment about the other two axes at the servo's horn face (what a single-sided joint's output shaft carries)
    and at the servo's centre (what a U-bracket's two arms carry as a force couple), axial and radial force."""
    import mujoco
    global _SP
    _SP = _SP or _servo_points()
    mujoco.mj_rnePostConstraint(m, d)
    c = d.subtree_com[0]
    for n in LOAD_JOINTS:
        j = mujoco.mj_name2id(m, mujoco.mjtObj.mjOBJ_JOINT, n)
        b = m.jnt_bodyid[j]
        a, p = d.xaxis[j], d.xanchor[j]
        tau_c, f = d.cfrc_int[b][:3], d.cfrc_int[b][3:]
        t_ax, f_ax = float((tau_c + np.cross(c - p, f)) @ a), float(f @ a)
        horn, centre = _SP[n[2:]]
        sg = -1.0 if (n[0] == "r" and n[2:] in ("hip_pitch", "knee", "ankle_pitch")) else 1.0

        def bend(off):
            q = p + a * sg * off
            tq = tau_c + np.cross(c - q, f)
            return float(np.linalg.norm(tq - (tq @ a) * a))
        vals = {"torque_nm": abs(t_ax), "bending_horn_nm": bend(horn), "bending_centre_nm": bend(centre),
                "axial_n": abs(f_ax), "radial_n": float(np.linalg.norm(f - f_ax * a))}
        if n.endswith("hip_yaw"):
            # the thrust ring alone (v0.4 before the keeper): it takes the bending only while the leg presses the disc
            # up into it; with the keeper, the ring and the keeper's lip hold the disc from both sides
            vals["yaw_shaft_ring_only_nm"] = max(0.0, vals["bending_horn_nm"] - max(0.0, -f_ax) * YAW_RING_R)
            Rp = d.xmat[m.body_parentid[b]].reshape(3, 3)
            q = p + a * horn
            Mp, fp = Rp.T @ (tau_c + np.cross(c - q, f)), Rp.T @ f
            L, N, shaft, _, _ = keeper_split(Mp[None, :2], np.array([-fp[2]]), keeper_arc(n[0]))
            vals.update({"yaw_shaft_residual_nm": float(shaft[0]), "yaw_keeper_lip_n": float(L[0]),
                         "yaw_ring_n": float(N[0])})
        pk = peaks.setdefault(n, {k: 0.0 for k in vals})
        for k, v in vals.items():
            pk[k] = max(pk[k], v)


class PerturbedWorld:
    """The robot program's I/O (send / tick / sleep / attitude / read_pose) on a randomly wrong physical robot: the
    same perturbations as trial(), but driven by jx0bot.robot.Robot itself, so whole missions can be tested."""

    def __init__(self, sc, seed):
        import mujoco
        import walk_jx0 as W
        from jx1calc.design import Design
        self.mj, self.W, self.sc, self.rng = mujoco, W, sc, np.random.default_rng(seed)
        design = Design(W.DESIGN)
        m = mujoco.MjModel.from_xml_string(W.build(design))
        oid = lambda kind, n: mujoco.mj_name2id(m, kind, n)  # noqa: E731
        torso = oid(mujoco.mjtObj.mjOBJ_BODY, "torso")
        m.body_mass[torso] *= sc["mass"]
        m.body_ipos[torso][:2] += np.array(sc["com_mm"]) * 1e-3
        for gname in ("l_foot_geom", "r_foot_geom", "floor"):
            m.geom_friction[oid(mujoco.mjtObj.mjOBJ_GEOM, gname)][0] = sc["mu"]
        ax, ay = (math.radians(v) for v in sc["slope_deg"])
        m.opt.gravity[:] = 9.81 * np.array([math.sin(ay) * math.cos(ax), -math.sin(ax), -math.cos(ax) * math.cos(ay)])
        self.m, self.d = m, mujoco.MjData(m)
        st = design.act_classes["ST"]
        self.servo = W.ServoModel(st["stall_torque_nm"] * sc["stall"], st["no_load_speed_rad_s"] * sc["stall"], 60.0 * sc["kp"], 0.6 * sc["kd"])
        from jx0bot.robot import ARM_JOINTS, LEG_JOINTS
        self.names = LEG_JOINTS + ARM_JOINTS
        self.adr = {n: (m.jnt_qposadr[oid(mujoco.mjtObj.mjOBJ_JOINT, n)], m.jnt_dofadr[oid(mujoco.mjtObj.mjOBJ_JOINT, n)]) for n in self.names}
        self.act = {n: oid(mujoco.mjtObj.mjOBJ_ACTUATOR, n) for n in self.names}
        self.goal = {n: 0.0 for n in self.names}
        self.lag = int(round(sc["latency"] * 0.02 / (1.0 / W.BUS_HZ)))
        self.pipe = deque(maxlen=self.lag + 1)
        self.bl = math.radians(sc["backlash_deg"]) / 2
        self.bias = [math.radians(v) for v in sc["bias_deg"]]
        self.fell, self.max_tilt = False, 0.0

    def settle(self, q0):
        mj, d = self.mj, self.d
        for n, v in q0.items():
            d.qpos[self.adr[n][0]] = v
            self.goal[n] = v
        mj.mj_forward(self.m, d)
        sole = min(d.site_xpos[mj.mj_name2id(self.m, mj.mjtObj.mjOBJ_SITE, s)][2] for s in ("l_sole", "r_sole"))
        d.qpos[2] -= sole - 0.001
        mj.mj_forward(self.m, d)
        self.pipe.extend([dict(self.goal)] * (self.lag + 1))

    def send(self, q):
        self.pipe.append({**self.goal, **q})
        self.goal_now = self.pipe[0]

    def read_pose(self):
        return {n: float(self.d.qpos[qa]) for n, (qa, _) in self.adr.items()}

    def attitude(self):
        r, p, y = self.W.rpy(self.d.qpos[3:7])
        n = math.radians(self.sc["imu_deg"])
        g = self.sc["gyro"]
        return (r + self.bias[0] + self.rng.normal(0, n), p + self.bias[1] + self.rng.normal(0, n), y,
                (self.d.qvel[3] + self.rng.normal(0, g), self.d.qvel[4] + self.rng.normal(0, g), self.d.qvel[5]))

    def tick(self, dt):
        self.advance(dt)

    def sleep(self, seconds):
        self.advance(seconds)

    def advance(self, seconds):
        goal = getattr(self, "goal_now", self.goal)
        for _ in range(int(round(seconds / self.m.opt.timestep))):
            for n in self.names:
                qa, da = self.adr[n]
                err = goal[n] - self.d.qpos[qa]
                err = 0.0 if abs(err) < self.bl else err - math.copysign(self.bl, err)
                self.d.ctrl[self.act[n]] = self.servo.torque(self.d.qpos[qa] + err, self.d.qpos[qa], self.d.qvel[da])
            self.mj.mj_step(self.m, self.d)
            r, p, _ = self.W.rpy(self.d.qpos[3:7])
            self.max_tilt = max(self.max_tilt, math.degrees(max(abs(r), abs(p))))
            if self.d.qpos[2] < 0.13 or self.max_tilt > 30:
                self.fell = True
                raise RuntimeError("fell")


MISSION = [("walk", {"steps": 8, "direction": "forward"}), ("turn", {"degrees": 40}), ("walk", {"steps": 4, "direction": "forward"}),
           ("walk", {"steps": 2, "direction": "left"}), ("walk", {"steps": 2, "direction": "backward"}),
           ("wave", {"arm": "right"}), ("nod", {"kind": "yes"}), ("look", {"direction": "left"})]


def mission(spec):
    """The robot program (jx0bot.robot.Robot) runs MISSION on a perturbed robot. Pass = it never falls."""
    from jx0bot.robot import REST_ARMS, Robot, load_config
    world = PerturbedWorld(spec["scenario"], spec.get("seed", 0))
    robot = Robot(world, load_config())
    world.settle({**robot.stand_pose, **REST_ARMS})
    done = []
    try:
        robot.stand(1.0)
        for name, args in MISSION:
            robot.act(name, args)
            done.append(name)
    except RuntimeError:
        pass
    return {"pass": not world.fell and len(done) == len(MISSION), "completed": done, "max_tilt_deg": round(world.max_tilt, 1),
            "distance_m": round(float(np.hypot(*world.d.qpos[:2])), 2), "latency_ms": spec["scenario"]["latency"] * 20}
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

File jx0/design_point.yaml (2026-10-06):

# JX0 design point — the small (~46 cm, ~2.8 kg) 3D-printed MVP humanoid. Same schema as calculations/design_point.yaml
# (JX1), so the JX1 analysis pipeline (jx1calc: parametric model, ZMP preview-control gait, whole-body IK, inverse
# dynamics) sizes it unchanged. Every value carries an evidence label: VERIFIED / MEASURED / CALCULATED / ESTIMATED /
# ASSUMED / UNVERIFIED. Masses are ASSUMED until the CAD mass properties replace them.
meta:
  version: "0.4"
  date: "2026-10-04"
  status: "v0.3 (2026-10-04): restyled after the reference robot (media/reference.mp4); all 17 joints Feetech STS3215 12 V; sage PETG; Raspberry Pi 4"

frames:
  convention: "ROS REP-103: x forward, y left, z up. Joint rotation positive by right-hand rule about the listed axis."
  pelvis_origin: "midpoint between the left and right hip centres (hip yaw/roll/pitch axes intersect at each hip centre)"
  zero_pose: "legs straight and vertical, feet flat and parallel, arms hanging, all joint angles 0"

overall:
  height_m: {value: 0.460, label: CALCULATED, note: "v0.4 CAD: sole 153 mm below the hip centres, head top 306.6 mm above"}
  mass_target_kg: {value: 2.0, label: ESTIMATED}

geometry:
  sole_to_ankle_m: {value: 0.033, label: CALCULATED, note: "v0.4 CAD: sole 5 mm + the ankle-roll servo's cage clearance at 20 deg roll; reference robot ~25 mm"}
  shin_m: {value: 0.058, label: CALCULATED, note: "v0.4 CAD: knee axis to ankle axis (reference robot ~46 mm); the ankle-pitch servo stands in a cage under the knee's U-bracket"}
  thigh_m: {value: 0.062, label: CALCULATED, note: "v0.4 CAD: hip centre to knee axis (reference robot ~63 mm); the knee servo lies forward so the thigh is the reference's dog-leg plate"}
  knee_actuator_z_m: {value: -0.062, label: CALCULATED, note: "knee servo on the knee axis (its case centre is 12.5 mm forward: actuator_offsets_m.knee)"}
  hip_spacing_m: {value: 0.090, label: ASSUMED, note: "two hip roll/pitch servo blocks side by side (servo body 45 x 25 mm)"}
  foot:
    length_m: {value: 0.124, label: CALCULATED, note: "v0.4 CAD foot x -68..56 mm: the roll U-bracket's rear arm sits over the heel"}
    width_m: {value: 0.070, label: CALCULATED}
    ankle_from_heel_m: {value: 0.068, label: CALCULATED, note: "CAD foot x -68..56 mm"}
    thickness_m: {value: 0.006, label: CALCULATED, note: "PETG sole 5 mm + 1 mm rubber"}
  torso:
    pelvis_to_shoulder_m: {value: 0.140, label: ASSUMED}
    shoulder_width_m: {value: 0.170, label: ASSUMED}

ankle_type: serial   # one servo per ankle axis (JX1 uses a two-motor parallel ankle)

# Joint order per leg: hip_yaw (z) -> hip_roll (x) -> hip_pitch (y) -> knee (y) -> ankle_pitch (y) -> ankle_roll (x).
# LEFT leg ranges in degrees; the right leg mirrors roll/yaw. Limits are set by the printed brackets (ASSUMED).
joint_ranges_deg:
  hip_yaw:     {min: -12,  max: 12,  label: CALCULATED, note: "+ = toes out (left leg); the yaw keeper and the hip-roll bracket are clear over +-12 deg (geometry.YAW_LIMIT, verify_cad); the gaits use +-5"}
  hip_roll:    {min: -20,  max: 22,  label: CALCULATED, note: "+ = abduction (left leg); CAD own-limb clear -22..25 (the roll U-bracket and the thigh meet the yaw disc)"}
  hip_pitch:   {min: -70,  max: 8,   label: CALCULATED, note: "- = flexion (leg forward); CAD clear -75 (thigh meets the hip-roll bracket) .. +12 (the hip-yaw bracket)"}
  knee:        {min: 0,    max: 84,  label: CALCULATED, note: "+ = flexion; CAD clear to 87 from the walking stance (75 with the hip straight: no action does that)"}
  ankle_pitch: {min: -55,  max: 15,  label: CALCULATED, note: "- = dorsiflexion (toes up); CAD clear -75..17"}
  ankle_roll:  {min: -20,  max: 20,  label: CALCULATED, note: "CAD own-limb clear -20..22 (the sole meets the roll servo's cage; the foot's bracket swings under the ankle bracket's arms)"}

# One actuator class for all 17 joints (legs, arms, neck): the Feetech STS3215 12 V serial bus servo (Evelta sells it as
# ST3215-C018; Waveshare as ST3215).
# Case 45.2 x 24.7 x 32 mm, 89 g (Waveshare drawing and product page); the cylinder model below only feeds the
# inertia estimate. Reflected rotor inertia ASSUMED: ~0.4 g·cm² rotor x (1:345 gearbox)^2 ≈ 0.005 kg·m² — hobby servos are
# NOT back-drivable, so this is large relative to the links; the sizing report shows its effect.
actuator_classes:
  ST: {mass_kg: 0.089, diameter_m: 0.035, length_m: 0.045, reflected_inertia_kgm2: 0.005,
       stall_torque_nm: 2.94, rated_torque_nm: 0.98, no_load_speed_rad_s: 4.72,
       product: "Feetech STS3215 12 V serial bus servo (ST3215-C018 / Waveshare ST3215; 30 kg·cm stall, 10 kg·cm rated at 12 V)", label: VERIFIED,
       note: "Waveshare product page: 30 kg·cm and 0.222 s/60 deg (45 rpm) at 12 V, 0.089 kg; Evelta: 10 kg·cm rated. Reflected inertia ASSUMED. research/raw/jx0_india_sourcing_raw.md"}
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

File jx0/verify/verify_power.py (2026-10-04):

"""JX0 electrical and timing checks.

1. Servo loads and current while walking and gesturing, from the simulation's actuator torques and joint speeds
   (the same servo model the gaits are verified with), per joint: peak / RMS torque vs the STS3215's 2.94 N·m stall and
   0.98 N·m rated torque, and current from the published electrical data (Waveshare ST3215 12 V: kt 11 kg·cm/A,
   no-load 0.2 A, stall 2.7 A).
2. Battery: total current at 12 V (17 servos + Pi 4 + audio), peak vs the 3S 35C pack, the 10 A switch and the UBEC;
   walking time from a 2200 mAh pack; compared with the reference robot's bench supply (0.6-1.5 A at 12.6 V).
3. Real-time budget of one 100 Hz robot frame: the bus packet time at 1 Mbit/s and the Python cost of the balance
   controller + command mapping, measured here and scaled for a Raspberry Pi 4.

    python jx0/verify/verify_power.py     -> jx0/results/verify_power.json
"""
from __future__ import annotations

import json
import math
import os
import sys
import time
from pathlib import Path

import numpy as np

ROOT = Path(__file__).resolve().parents[2]
sys.path.insert(0, str(ROOT / "jx0" / "sim"))
sys.path.insert(0, str(ROOT / "jx0" / "software"))
os.environ.setdefault("JX0_STL_DIR", str(ROOT / "nonexistent"))
OUT = ROOT / "jx0" / "results" / "verify_power.json"

KT = 11 * 0.0980665          # N·m per A (11 kg·cm/A)
I0, I_STALL = 0.20, 2.7      # A (no-load current is at full speed; a servo holding still draws only its electronics)
V_SERVO = 12.0
R_MOTOR = V_SERVO / I_STALL  # ohm: the motor's winding resistance from the stall current
I_IDLE = 0.02                # A per servo, electronics (ESTIMATED; checked against the reference robot's standing current)
STALL, RATED = 2.94, 0.98    # N·m
V_BATT = 11.1                # V nominal 3S
PI_W, AUDIO_W = 4.0, 1.0     # Raspberry Pi 4 under load (ESTIMATED), mic + amplifier idle/average (ESTIMATED)
PACK_AH, PACK_C = 2.2, 35


def servo_current(tau, w):
    """Supply current of one PWM-driven servo: the motor needs i = tau / kt; the supply delivers the copper loss i²R plus
    the mechanical power tau·w (none back when braking), plus the electronics."""
    i_m = abs(tau) / KT
    p = i_m * i_m * R_MOTOR + max(0.0, tau * w)
    return I_IDLE + p / V_SERVO


def stand_current(seconds=2.0):
    """Servo supply current with the robot standing still in the walking stance (compare: the reference robot's bench
    supply read 0.58 A at 12.6 V standing)."""
    import mujoco
    import walk_jx0 as W
    from jx1calc.design import Design
    design = Design(W.DESIGN)
    m = mujoco.MjModel.from_xml_string(W.build(design))
    d = mujoco.MjData(m)
    g, res = W.plan(m, design, "forward_2")
    q0 = res["qpos"][0]
    st = design.act_classes["ST"]
    names = [f"{s}_{j}" for s in "lr" for j in W.LEG_JOINTS] + [f"{s}_{j}" for s in "lr" for j in W.ARM_JOINTS] + ["neck_yaw"]
    oid = lambda k, n: mujoco.mj_name2id(m, k, n)  # noqa: E731
    adr = {n: (m.jnt_qposadr[oid(mujoco.mjtObj.mjOBJ_JOINT, n)], m.jnt_dofadr[oid(mujoco.mjtObj.mjOBJ_JOINT, n)]) for n in names}
    act = {n: oid(mujoco.mjtObj.mjOBJ_ACTUATOR, n) for n in names}
    servo = W.ServoModel(st["stall_torque_nm"], st["no_load_speed_rad_s"], 60.0, 0.6)
    d.qpos[:] = q0
    for n, v in W.arm_goals(q0, q0, adr).items():
        d.qpos[adr[n][0]] = v
    mujoco.mj_forward(m, d)
    goal = {n: float(d.qpos[adr[n][0]]) for n in names}
    cur = []
    for k in range(int(seconds / m.opt.timestep)):
        total = 0.0
        for n in names:
            qa, da = adr[n]
            u = servo.torque(goal[n], d.qpos[qa], d.qvel[da])
            d.ctrl[act[n]] = u
            total += servo_current(u, d.qvel[da])
        mujoco.mj_step(m, d)
        if k > seconds / m.opt.timestep / 2:
            cur.append(total)
    return float(np.mean(cur))
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

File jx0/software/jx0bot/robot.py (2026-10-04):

"""JX0 body: joint I/O (real hardware or the MuJoCo model), verified gait playback with IMU balance, and the actions
the brain can call (wave, nod, look, walk, turn).

Every joint is a Feetech STS3215 12 V serial bus servo (12 legs, 2 per arm, the neck), all on one bus, so both back
ends take the same joint targets (radians, the simulation's sign convention):
- HardwareIO: the 17 servos through the serial bus servo driver (servo_bus.py), MPU6050 IMU.
- SimIO: the JX0 MuJoCo model (jx0/sim/jx0_model.py) with the same servo model the gaits were verified with; runs on a
  PC (python -m jx0bot.main --sim) so the whole robot, voice included, can be tried before it is built.
Gaits (gaits/*.json) are 100 Hz trajectories (legs plus the arm swing) exported by jx0/sim/walk_jx0.py after passing
the closed-loop test.
"""
from __future__ import annotations

import json
import math
import threading
import time
from pathlib import Path

import yaml

from .balance import Balance

HERE = Path(__file__).resolve().parent
LEG = ["hip_yaw", "hip_roll", "hip_pitch", "knee", "ankle_pitch", "ankle_roll"]
LEG_JOINTS = [f"{s}_{j}" for s in "lr" for j in LEG]
ARM_JOINTS = [f"{s}_{j}" for s in "lr" for j in ("shoulder_pitch", "elbow")] + ["neck_yaw"]
REST_ARMS = {"l_shoulder_pitch": 0.0, "r_shoulder_pitch": 0.0, "l_elbow": math.radians(-20), "r_elbow": math.radians(-20)}


def load_config(path: Path = HERE / "config.yaml") -> dict:
    return yaml.safe_load(Path(path).read_text(encoding="utf-8"))
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

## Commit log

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2026-09-23 Add parametric leg dynamics analysis engine (iteration 0)
    Closed-form 6-DOF leg IK (verified vs MuJoCo FK to 1e-9), LIPM ZMP preview
    control with multibody two-stage correction, floating-base inverse dynamics
    with contact-wrench distribution, parallel-ankle linkage mapping, static
    worst-case poses and requirement policy. Iteration-0 results use ASSUMED
    masses and dimensions.
    [static_cases.csv, timeseries_squat_0.20m_1.6s.csv, timeseries_turn_15deg_per_step.csv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]
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2026-09-23 Select RobStride actuator classes and build full left-leg part set
    Research evidence from six sourcing/reference studies (India suppliers, actuator
    technology, reference humanoids, power, electronics/compute, mechanical).
    Iteration-1 design point: RS03 (L) hip pitch/roll/knee, RS06 (M) hip yaw and
    parallel-ankle pairs, RS02/RS00 for arms; thigh 0.27 m, shin 0.30 m, hip
    spacing 0.20 m; ankle crank 50 mm / foot lever 40 mm verified reachable over
    -55..+35 deg pitch and +-20 deg roll (cond(J) <= 1.17).
    Native parametric CAD rebuilt: four actuator interface classes, pelvis, hip
    yaw/roll brackets, thigh, shin, ankle cross, foot, crank and push rods - all
    single bodies, zero rebuild errors, every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
    [JX1_ACT_L_Housing.SLDPRT, JX1_ACT_L_Output.SLDPRT, JX1_ACT_M_Housing.SLDPRT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]
2026-09-23 Articulated SolidWorks pelvis + left leg with verified kinematics
    Assembly of 24 components and 40 mates: LOCK for bolted joints, coincident
    axis + face mates for every revolute joint, limit-angle mates created with the
    joint axis as reference direction (signed, deterministic windows inside
    0-180 deg; hip-pitch/knee outputs clocked 45 deg), passive ankle universal
    joint and a closed parallel-ankle linkage (cranks + ball-jointed push rods).
    Joint limits are driven through the hip/knee mates and the two ankle motors.
    Motion verification: 25 poses (every joint min/zero/max + multi-joint poses)
    match the analytic kinematics to 0.0000 mm / 0.0000 deg, including the
    SolidWorks-solved ankle linkag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
    [JX1_ACT_L_Housing.SLDPRT, JX1_ACT_L_Output.SLDPRT, JX1_ACT_M_Housing.SLDPRT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]
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2026-09-23 Add requirements, architecture/safety docs, CAN hub firmware and sim tooling
    - requirements/robot_requirements.yaml: living requirements with status per item
    - docs/: architecture, safety architecture (E-stop, fusing, BMS, watchdogs),
    risk register R1-R16, open issues OI-1..OI-13
    - actuators/: selection rationale and modular actuator interface spec
    - firmware/hub: Teensy 4.1 CAN hub (RobStride private protocol codec from the
    official manuals, 500 Hz bus schedule, host CRC16 protocol, host/CAN
    watchdogs, E-stop and fault latching -> damping); generated per-hub configs
    - tools/sim + simulation/mujoco + ros2_ws + simulation/isaac: CAD-to-URDF/MJCF
    pipeline, MuJoCo validation harness, jx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
    [robot_requirements.yaml]
2026-09-23 Rebuild both legs with RS04 hip-pitch/knee classes; verify L and R in SolidWorks
    - CAD: XL (RS04) actuator envelopes, right-leg parts (mirrored builders), full
    JX1_LowerBody assembly (pelvis + both legs, 12 actuated joints + closed ankle
    linkages) rebuilt from the parametric scripts
    - thigh C-channel flanges now end 4 mm above the knee housing (the larger RS04
    housing overlapped them by 0.8 mm -> 16.5 mm3 per flange)
    - verification: both legs pass kinematics 25/25 (SolidWorks mate solution ==
    analytic FK to 0.0000 mm / 0.0000 deg); 24/25 poses collision-free per leg,
    remaining contact is the known ankle corner (+30 pitch / -20 roll, OI-3);
    inter-leg contact only at hip-roll max a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
    [JX1_ACT_L_Housing.SLDPRT, JX1_ACT_L_Housing.STL, JX1_ACT_L_Output.SLDPRT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]
2026-09-24 Structural FEA of the leg: printed brackets fail, redesign in 6061/7075
    - calculations/structural: validated voxel FEA (hex8 incompatible modes,
    RBE3 wrench loads, geometric-multigrid PCG; patch test exact, cantilever
    deflection 1.2 %, bending stress 1.9 %), print-orientation-aware failure
    index for PA-CF, Goodman fatigue, sourced allowables (6061/7075/eSUN PA-CF)
    - physically consistent loads (leg_loads.py): 2160 ground-reaction samples
    at 3 BW scaled to actuator saturation + walking/turning time series
    - result: every printed primary-load part fails (SF 0.07-0.89); design
    changes: 7075 hip-yaw bracket with 12 mm back plate + keel (Y13 1.87/1.60),
    6061 10 mm hip-roll bracket, 10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
    [master_bom.csv]
2026-09-24 Phase-2 upper body CAD pipeline, whole-robot assembly, wiring and fixes
    - tools/cad: upper-body kinematic model (UpperCAD, mirrors joint_map; limit
    windows centred by output clocking), parametric builders for the torso
    frame (6061 plates + 2020 posts, battery/Jetson/hub/DC-DC/E-stop
    envelopes), RS02/RS00 arm brackets, gripper, ST3215 neck and head,
    upper-body assembly with +0.1 rad sign checks, whole-robot assembly
    (JX1_Robot: legs + upper body, 23 joints) and whole-body pose verifier,
    manufacturing package exporter (STEP, A3 drawings, print STLs)
    - shoulder roll actuator moved back to x = -40 mm (the plate clashed with
    the RS00 shoulder-yaw housing); hip-roll back plate kept a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
    [design_point.yaml]
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2026-09-24 Aluminium leg parts rebuilt; arm connector clocking, head chamfer, FEA results
    - Leg parts regenerated in SolidWorks after the FEA-driven redesign: 7075 hip-yaw bracket
    with 12 mm back plate and keel, 6061 hip-roll (8/10 mm), thigh (10 mm plate, run-out
    flanges), shin (14 mm knee plate, joggle), foot (8 mm sole), pelvis box (6/4/4 mm).
    - Upper body: right shoulder-roll and left shoulder-yaw housings clocked 180 deg so the
    connectors face outward (clashed with the pitch bracket: 1260 / 83 mm3), E-stop contact
    block moved 5 mm inboard, shoulder-roll pilot recess cut after the yaw plate (re-filled
    40 mm3), head rear-bottom chamfer (touched the back plate looking up + yawed back).
    - se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
    [JX1_AnkleCrank.SLDPRT, JX1_AnkleCross.SLDPRT, JX1_AnkleRod_A.SLDPRT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]
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2026-09-24 Upper body verified in SolidWorks: 36/36 poses exact and collision-free
    JX1_UpperBody.SLDASM rebuilt with the fixed parts (43 components, 64 mates, no mate errors,
    all 11 joint signs match the analytic model). verify_upper_motion: every single-joint
    limit (min/max) and 13 combined poses (T-pose, reach up, arms back, hands together, carry,
    wave, waist twist, head scans) at 0.0000 mm / 0.0000 deg against upper_kinematics.py with
    zero interferences (previously 0/36: connector clocking, E-stop, pilot recess, head).
    Pose images now rendered with a Z-up camera.
    [JX1_BatteryPack.SLDPRT, JX1_DCDC5V.SLDPRT, JX1_EStop.SLDPRT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]
2026-09-24 Legs re-verified after the aluminium redesign; hip-roll back plate clearance
    - verify_leg_motion found the thigh back flange touching the hip-roll back plate's lower
    edge at hip pitch +35 deg (0.23 mm3, both sides; first contact between 34.5 and 35 deg,
    SolidWorks interference body at bracket (-68.1, 25, -44.9) mm). The back plate's lower
    edge moves from z -45 to -40 mm (PKG roll_back_bottom_z, global variable Back_bottom_z):
    first contact ~37.3 deg, output disc still fully covered.
    - JX1_LowerBody rebuilt (no mate errors, all joint signs OK). Left and right legs: 25/25
    poses at 0.0000 mm / 0.0000 deg vs the analytic model; collision-free 24/24 within the
    coupled ankle limits. Th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
    [JX1_HipRollBracket_L.SLDPRT, JX1_HipRollBracket_R.SLDPRT, JX1_LowerBody.SLDASM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]
2026-09-24 Whole-robot SolidWorks assembly (87 components, 140 mates) and fresh part meshes
    JX1_Robot.SLDASM: legs + upper body articulated together, no mate errors, all joint signs
    match the analytic models. simulation/meshes/source_mm re-exported from the final parts
    (46 parts, mesh volume within 1 % of SolidWorks).
    [JX1_BatteryPack.STL, JX1_DCDC5V.STL, JX1_EStop.STL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]
2026-09-24 Whole robot verified: 13/13 poses exact, collision-free within the documented limits
    verify_robot_motion on JX1_Robot.SLDASM (legs + upper body driven together): every pose at
    0.0000 mm / 0.0000 deg against the leg and upper-body analytic models; 11/11 poses inside the
    controller limits collision-free. single_leg_T_pose now uses stance adduction 8 deg (OI-7)
    with the swing leg abducted; the old 14 deg over-shift (legs cross) and arms-down + 30 deg
    abduction (thigh/gripper, OI-18) are kept as negative tests and flagged
    outside_documented_limits. Z-up iso/front/side images.
    [robot_motion_verification.csv]
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2026-09-24 Trainable JX1: MuJoCo RL pipeline, Isaac Lab task, ROS 2 sim + policy packages
    - rl/: batched MuJoCo environment on the CAD-derived model (mujoco.rollout thread pool,
    ~20k policy steps/s on 8-11 CPU threads): capsule/box collision fitted to the CAD hulls,
    deployment PD gains, legged_gym-style velocity-tracking rewards with gait clock, domain
    randomisation (16 physics variants), pushes, ankle targets projected into the SolidWorks
    collision-free pitch/roll polygon. PPO with asymmetric actor-critic (rsl_rl algorithm) on
    the GPU, export to TorchScript + ONNX + policy_io.yaml, sim-to-sim on the full CAD model.
    Solver line search must be >= 20 iterations (10 injected energy after falls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
    [controllers.yaml, jx1.ros2_control.xacro, jx1_system.urdf.xacro]
2026-09-24 Interim JX1 walking policy: MuJoCo-trained, verified on the CAD model and over ROS 2
    Policy rl/policies/jx1_walk_flat (1500 PPO iterations, 37M steps, ~38 min on the laptop;
    trained on the current CAD MJCF with the placeholder torso - to be fine-tuned on the final
    CAD model when it is regenerated):
    - sim-to-sim on the full CAD model (mesh-hull collisions, 500 Hz, no randomisation),
    7/7 scenarios upright, max tilt 8.4 deg: forward 0.5 -> 0.523 m/s, 0.8 -> 0.787,
    backward 0.3 -> 0.311, side-step 0.2 -> 0.181, turn 0.5 -> 0.502 rad/s,
    walk+turn (0.4, 0.3) -> (0.423, 0.278). Ankle pitch peaks at 87-100 % of its 46 N m
    linkage limit when walking - a torque-headroom penalty is added for th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
    [metrics_walk_v1_warmstart.csv]
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2026-09-24 BOM: torso and arms are 6061 plate (FEA), PA-CF only for small parts
    Torso (6061 SF 4.44/3.59; PA-CF 0.70/0.42) and all arm parts (6061 passes, every PA-CF
    print variant fails at 0.12-0.56) move from in-house prints to laser-cut 6061 plate
    (ESTIMATED Rs 3,000 + Rs 6,000, quotes required). PA-CF filament 3 -> 1 kg (neck bracket,
    grippers); PETG-CF 3 -> 4 kg incl. fit-check copies of the metal parts. Robot total
    Rs 7,12,481 (+15 % = Rs 8,19,353); actuators 77 %.
    [master_bom.csv]
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2026-09-24 Manufacturing package, redesigned upper arm and foot, SolidWorks materials
    - manufacturing/: 24 STEP files (quote/CAM master), 14 A3 PDF drawings (views, material,
    process, qty, ISO 2768-m, envelope, SolidWorks mass, cylindrical-feature list),
    24 PETG fit-check STLs (not structural), 3 print STLs, index.md. SLDDRW in CAD/Drawings.
    - Every machined part carries its SolidWorks library material (6061-T6 (SS), 7075-T6 (SN),
    AISI 1045) and linked title-block properties (OI-5).
    - Upper arm L/R rebuilt as variant U3 (10 mm elbow plate, 8 mm yaw plate, 2 gussets);
    foot L/R with the lightening hole moved off the front clevis tine.
    - JX1_UpperBody re-verified with the new arms: 36/36 exact, 36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
    [JX1_AnkleCrank.SLDDRW, JX1_AnkleCrank.SLDPRT, JX1_AnkleCrank.STEP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]
2026-09-24 Final structural analysis of the whole robot on the final CAD
    All structural parts pass in aluminium (SF static / fatigue, required 1.5 / 1.5):
    hip yaw 7075 1.77/1.58, hip roll 2.76/3.80, thigh 2.31/2.78, shin 3.37/4.17, foot
    3.50/2.03, pelvis 2.90/3.44, crank 14.4/24.7, torso 4.44/3.59, shoulder pitch 2.17/1.75,
    shoulder roll 2.05/1.66, upper arm (redesigned) 5.99/4.84, forearm 3.27/2.65.
    Every upper-body part evaluated as a PA-CF print fails (static 0.23-1.23 vs 2.0).
    Docs, BOM and builder notes carry the final-CAD numbers.
    [master_bom.csv]
2026-09-24 Isaac Lab tasks checked offline against Isaac Lab 2.3.2 + rsl_rl 3.1.2 (77/77); fix ONNX export without normaliser
    offline_check.py imports the real Isaac Lab sources with the Omniverse modules mocked and, for all four JX1 tasks:
    instantiates and validates the configs, resolves every manager term like Isaac Lab does at start-up, evaluates every
    observation/reward/termination term on a fake scene checked against the real data classes, compares the policy and
    critic observations and the action targets (clamp, ankle polygon, hub ramp, delay, reset) with the MuJoCo task, and
    checks script imports/keywords and the exporter against rsl_rl's ActorCritic.
    Fixes found by it:
    - export_policy.py wrote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
    [robot.py]
2026-09-24 v0.5: final robot model, simulation evidence, iteration-2 margins, docs
    - Robot description regenerated from the final CAD: 33.61 kg, 25 bodies, 23 actuated
    joints; URDF + xacro (29 links, expansion matches the URDF), MJCF, Isaac import config.
    - MuJoCo on the CAD model: standing held (max tilt 5.2 deg, no saturation), squat
    (tracking 4.95 deg), ZMP walking 4/4 gaits (slow/nominal/fast/turn), push recovery
    5.3-7.8 N s (fixed footsteps).
    - Iteration-2 leg analysis with CAD masses: slow/nominal walking (<= 0.52 m/s), turning
    and squat meet the 1.5x torque policy; the 0.79 m/s gait needs 37.0 N m hip yaw vs RS06
    36 N m (OI-2: speed cap ~0.6 m/s or RS03 hip yaw). Power: 92 W standing,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
    [head_link.stl, head_link_c0.stl, head_link_c1.stl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]
2026-09-24 Final flat walking policy on the final 33.61 kg model; ros2_control path verified; sim bring-up gantry
    Policy jx1_walk_flat = walk_v2_final iteration 3000 (fine-tuned on the final CAD model after the arm redesign):
    - CAD model sim-to-sim: all 7 scenarios upright (flat and rough heightfield); 0.50 m/s at 0.5, 0.78 at 0.8, 0.47 rad/s at 0.5
    - command envelope: 99/130 commands tracked, 0 falls; forward 1.13 m/s (torque-limited), backward 0.59, lateral
    0.37/0.25, yaw 0.85/0.82 rad/s
    - push recovery at 0.5 m/s: 21.6 / 14.5 / 12.7 / 17.8 N s (fwd/back/left/right)
    - ROS 2: python -m, ros2 launch mujoco_sim.launch.py and ros2 launch ros2_control.launch.py (controller_manager +
    topic_based_ros2_c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
    [metrics_walk_v2_final.csv]
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2026-09-24 Rough-ground policy jx1_walk_rough (walk_v3_rough, 1000 iterations on the heightfield from the final flat policy)
    Best policy so far, on the final 33.61 kg CAD model:
    - sim-to-sim flat and rough heightfield: 7/7 upright; 0.8 m/s commanded -> 0.79 / 0.80 m/s at 71-73 % peak torque
    (flat policy 90-95 %, hubs cap at 80 %); turn 0.5 -> 0.49 rad/s; no yaw drift at standstill (0.007 rad/s)
    - command envelope 109/130 tracked (flat floor), 108/130 (rough), 0 falls; forward 1.09 m/s at 85 % torque
    - push recovery at 0.5 m/s: 32.8 / 35.6 / 15.9 / 44.1 N s fwd/back/left/right (flat policy 21.6/14.5/12.7/17.8)
    - latency: 0.3 rad/s turn tracked 101 % without delay, 89 % at 40 ms sensing + 20 ms actuati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
    [metrics_walk_v3_rough.csv]
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2026-09-24 Self-contact of the learned gait on the CAD hulls (OI-7 legs, OI-24 hip-yaw brackets, OI-18 arm-thigh) in sim2sim, the command envelope, REPORT.md and the policy comparison
    Every contact between two robot bodies is counted per policy step (the CAD MJCF collides every non-adjacent body pair).
    Detector check: 22 deg toe-out on each hip reports left_hip_yaw_link|right_hip_yaw_link, 20 deg none (OI-24 sweep: 21).
    [report.py]
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2026-09-24 Docs follow the new default policy jx1_walk_stand_v7: OI-27 resolved in sim (stands still at 73 W, 5.1 h), OI-2/7/21/23/26 figures, final spec regenerated, README, risk register, assembly guide and t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
    [make_cost_report.py]
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2026-09-24 JX0 (the <₹50k MVP humanoid) begins: design point, servo sizing on the JX1 gait/inverse-dynamics pipeline, and the talking/servo software
    - jx0/design_point.yaml: 46 cm, 1.81 kg, 12-DOF legs on ST3215 bus servos, serial ankle, PETG structure (masses ASSUMED)
    - jx0/analysis/sizing.py: ZMP walking, turning, squat and single-leg poses -> all 12 leg joints pass
    (hip roll tightest: 1.41x peak margin, 84 % of the torque-speed line at 4 cm / 0.6 s steps); faster steps exceed the
    servo's ~4.7 rad/s, so JX0 walks at 5-7 cm/s
    - jx1calc: optional layout block and serial ankle (JX1 results unchanged, mass tables identical)
    - jx0bot: Claude brain (claude-opus-5, streamed sentence-by-sentence, robot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
    [design_point.yaml, servo_bus.py]
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2026-09-24 JX0 in SolidWorks: 21 native parametric printable parts + 40-component robot assembly, STLs for printing, and the ₹46,858 parts list
    - jx0/cad/geometry.py: every part in its link frame around the Waveshare/Feetech ST3215 interface from the official
    2D drawing (45.22 x 24.72 x 32 mm case, Ø19.2 horns on a 14 mm hole circle, rear-face mounting pattern); single-sided
    joints, all hip axes meet at the hip centre, both ankle axes at the ankle centre (as the gait model assumes)
    - jx0/cad/build_cad.py: offset planes + fully defined sketches + extrudes/cuts in the dedicated SolidWorks session; each
    part checked (one solid body, no rebuild errors, bounding box = geometry) and exported to STL;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
    [JX0_AnkleBracket_L.SLDPRT, JX0_AnkleBracket_L.stl, JX0_AnkleBracket_R.SLDPRT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]
2026-09-24 JX0 walks as the SolidWorks robot: CAD masses and 12 V servos fed back, sim uses the CAD meshes, 6/6 gaits pass
    - design_point v0.2: Feetech ST3215-C018 12 V (30 kg·cm stall, 10 kg·cm rated, 0.089 kg, VERIFIED), printed-part masses
    from SolidWorks, servo positions from the CAD; total 2.01 kg, 50.5 cm
    - sizing: all 12 leg joints pass (hip roll tightest: 1.93x peak margin, 60 % of the torque-speed line)
    - jx0/cad/layout.py: one component layout for the SolidWorks assembly and the MuJoCo model (meshes at the CAD poses)
    - walking on the servo model: the heavier CAD robot needs servo stiffness 60 N·m/rad and damping 0.6 N·m·s/rad
    (softer or less damped servos drift or fall); then forward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
    [design_point.yaml]
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2026-09-24 JX0 CAD rebuilt on camera: SolidWorks timelapse of all 21 parts + the 40-component assembly
    - build_cad.py / build_assembly.py --frames: exports the SolidWorks model view after every feature and every placed
    component (works with the window covered), then a 48-frame turntable of the finished robot
    - 380 frames -> media/jx0_cad_timelapse.mp4 (33.7 s, 12 fps); all parts rebuilt with errors none, bbox OK
    - pelvis rebuilt with every cut applied: 21.2 g printed (was 23.3 g)
    [JX0_AnkleBracket_L.SLDPRT, JX0_AnkleBracket_R.SLDPRT, JX0_Foot.SLDPRT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]
2026-09-24 JX0: all 14 gaits re-verified (walking.json now lists the gait blocks); PETG note 351 g from the CAD; stale design-point notes fixed
    [jx0_bom.csv]
2026-09-24 JX0 gets working hands and a real face: MG90S gripper claws, round-screen face head, both in SolidWorks, sim and software
    Hands
    - each forearm is now a hand: the gripper MG90S sits in a sleeve, a 3-finger claw (JX0_Finger_L/R) on its horn closes
    against a 3-finger palm; opens ~45 mm at 60 deg. 2 more MG90S (GPIO 4, 26): BOM Rs 47,106 (still under Rs 50k)
    - fixed an old CAD clash: the upper arms sat 4 mm inside the torso side walls at the zero pose; shoulder-roll axis
    moved 7 mm outboard (ARM_Y 17), shoulder bracket bridged and lightened
    - software: hand tool for Claude (open / close / take / give), wave opens the hand, grip rests 5 deg open
    Face
    - new head: rounded top, ears with vents,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
    [JX0_Display_GC9A01.SLDPRT, JX0_Display_GC9A01.stl, JX0_Finger_L.SLDPRT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]
2026-09-24 JX0 docs: overview README, build guide, wiring, bring-up, software setup, and a 4-page cost estimate PDF
    - jx0/README.md: what JX0 does, honest status, specs, cost by group, how it works, try it on a PC, how it was checked
    - docs/build_guide.md: 23 prints with masses and print tips, the joint-by-joint assembly order, fasteners
    - docs/wiring.md: power tree (mermaid), servo bus IDs, the full GPIO map (9 MG90S incl. grippers, SPI face, I2S audio)
    - docs/bringup.md: IDs, centring, zero pose, directions, stiffness, first steps, display self-test
    - docs/software_setup.md: PC simulation, Pi OS, I2S overlay, Vosk/Piper models, Claude key, systemd service
    - bom/make_cost_report.py -> JX0_cost_estimat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
    [jx0_bom.csv]
2026-10-04 JX0 v0.3: restyled after the reference robot, every joint a Feetech STS3215 12 V
    The user's friend's robot (12 V STS3215 everywhere, pastel green print, faceted body) is the new target:
    - 17 STS3215 on one serial bus (12 legs, shoulder pitch + elbow per arm, neck); MG90S, grippers, round screen,
    camera and the 5 V servo buck removed. Evelta Rs 2,419, 48 in stock today. Parts list Rs 58,548 (user OK'd > 50k)
    - CAD (SolidWorks by script, 20 printed parts + 17 servos, all one body, no errors): octagonal torso split into a
    lower shell and a vented chest cap with chamfered top edges, exposed neck STS3215 under a soft rounded head with four
    face holes (microphone), shoulder cradles holding t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
    [JX0_AnkleBracket_L.SLDPRT, JX0_AnkleBracket_L.stl, JX0_AnkleBracket_R.SLDPRT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]
2026-10-04 JX0 v0.3 finished: true-arc CAD, push test, reference-style demo film, docs and cost PDF
    - SolidWorks: rounded profiles are now real arcs (swlib Sketch.profile: lines + 3-point arcs, merged endpoints), so
    the head, blades, cradles, leg plates and feet are smooth; 20 printed parts, one body each, no errors, 415 g; the
    37-component assembly with all 17 STS3215
    - walk_jx0: 14/14 gaits pass on the final CAD; new push test (sideways shove on the torso mid-walk): survives
    0.72 N.s, falls at 1.08 N.s, recorded in walking.json; earlier 1.1 N.s claim corrected (it was between steps)
    - demo film staged like the reference video: wood floor, filament box, bottle; walks with arm swing, waves, takes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
    [JX0_ArmBlade_L.SLDPRT, JX0_ArmBlade_L.stl, JX0_ArmBlade_R.SLDPRT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]
2026-10-04 JX0 verified: CAD collisions, joint limits, robustness, power, timing and software tests; 9 problems found and fixed
    New jx0/verify/ (python jx0/verify/run_all.py -> jx0/results/verification.md):
    - verify_cad.py: exact CAD solids (manifold3d), 666 component pairs at rest, 1,373 moving poses (every gait frame +
    every action), every joint swept through its limits. Found: shoulder servos inside the chest cap (696 mm3), hip
    gusset into the hip-pitch servo (36 mm3, since v0.1), foot grazing the ankle-pitch servo in 341 walking poses,
    ankle roll hitting the ankle bracket >14 deg, ankle brackets touching in side-steps, joint limits allowing
    collisions. Fixed: cap +5 mm, gusset trimmed, ankl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
    [JX0_AnkleBracket_L.SLDPRT, JX0_AnkleBracket_L.stl, JX0_AnkleBracket_R.SLDPRT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]
2026-10-04 JX0: everything re-verified from a clean run; final masses, 100 Hz docs, end-to-end main-program test
    - clean python jx0/verify/run_all.py on the final design: sizing ALL PASS, 14/14 gaits, 0 CAD clashes (666 pairs,
    1,373 moving poses), 17/17 joint limits clear, 97 % of 140 walks with realistic model errors, 24/24 missions,
    pushes 100 % at 0.24 N.s, power PASS (1.52 A walking, ~70 min), 20/20 software tests
    - new test: jx0bot.main end to end (text mode, simulated body, scripted Claude): 'walk forward two steps' walks
    the robot forward and the reply is spoken
    - exact CAD masses fed back (chest cap 52.1 g, head 66.8 g): robot 2.44 kg; build guide table, totals (419 g), README
    - the repor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
    [jx0_bom.csv]
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
